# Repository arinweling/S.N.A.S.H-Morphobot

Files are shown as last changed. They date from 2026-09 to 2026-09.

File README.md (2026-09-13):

<!-- DON'T MODIFY ANYTHING ABOVE -->

<!-- Modify from here -->
<!-- ### EDL 2025 Project Submission Repository.

Change this file to include the relevant information of your project. Refer to SUBMISSION_INSTRUCTIONS.md file and follow it for your final submission. Make sure to pass the GitHub Actions. (The Docs Added should turn green and it should say "passing") -->

https://github.com/user-attachments/assets/5dc95bf6-1b18-49de-8811-edd3fce2244d

# S.N.A.S.H. - Your Friendly Neighbourhood MorphoBot
## MON-10
## Team Members:
- Sthiti Padhi
- Neel Bhavesh Rambhia
- Arin Prashant Weling
- Saumya Dharmesh Shah
- Harshil Singla

## Problem Statement and Solution:
### Problem Statement
Robots designed exclusively for ground travel or aerial operation often encounter significant challenges when faced with unpredictable or mixed environments. Ground-based robots may be unable to overcome obstacles or reach elevated areas, while aerial robots are limited by battery constraints and inefficiency during extended ground operations.

The problem is to create a robotic platform that can seamlessly transition between driving and flying, allowing it to navigate a wide range of terrains and obstacles efficiently. The system should provide the user with the ability to switch modes as needed to maximize energy efficiency and reach locations that would be inaccessible to single-mode robots.

### Solution
We developed **S.N.A.S.H.**, a multi-modal robotic system capable of:

- **Driving**: Increasing battery life and locomotive abilities for ground traversal.
- **Flying**: Quadcopter mode helps navigate over obstacles or difficult terrain.
- **Morphing**: A custom servo setup to switch between drive and drone configurations.

The system is controlled by a single flight controller that dynamically switches outputs to:
- 1 motor driver (controlling two motors via IN1 and two motors via IN2) (drive mode)  
- 4-in-1 ESC on SpeedyBee (flight mode)
- 4 Servo motors from their dedicated PCBs
based on mode-switch commands from the user through the RC transmitter.

### Folder Structure:
```plaintext
/Project-Root
├── /others
    ├── future_work.md/
    ├── learnings_takeaways.md/
    ├── user_manual.md/
    ├── README.md/
 
├── /3d_models               # laser cuts and 3d prints
    ├── Chassis/
    ├── Wheel_Assembly/
    ├── README.md/          
 
├── /pcb                    # pcb design files
    ├── PCB1/
    ├── Resources/
    ├── README.md/

├── /milestone reports

├── /inav

├── /Ardupilot                    # source folder
    ├── ArduCopter/         # we used ArduCopter and added files here
        ├── Copter.cpp
        ├── mode.cpp
        ├── mode_drive.cpp
        ├── mode_morph.cpp
        ├── mode_stabilize.cpp
        ├── README.md/      # describes the changes made, marked as 'EDL-MON10'
        └── ...
    
    ├── ArduPlane/  
    
    ├── ArduRover/
    
    ├── libraries/          # modified hwdef for gpio, default params
        ├── AP_HAL/
        ├── AP_HAL_ChibiOS/
        ├── AP_Motors/      # To use extra motor output or change motor functions - to be done here
        └── ...
    
    ├── modules/            
    
    ├── Tools/              # Developer tools, test scripts, MAVProxy, etc.
    
    ├── build/              # Build scripts and configuration
    
    ├── docs/               # Documentation
    
    ├── wscript             # Waf build system entry point
    └── README.md           # Project overview and setup instructions

```

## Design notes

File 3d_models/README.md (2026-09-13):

# 3D Models
This directory contains all the STEP files used for the mechanical design of the Morphobot.

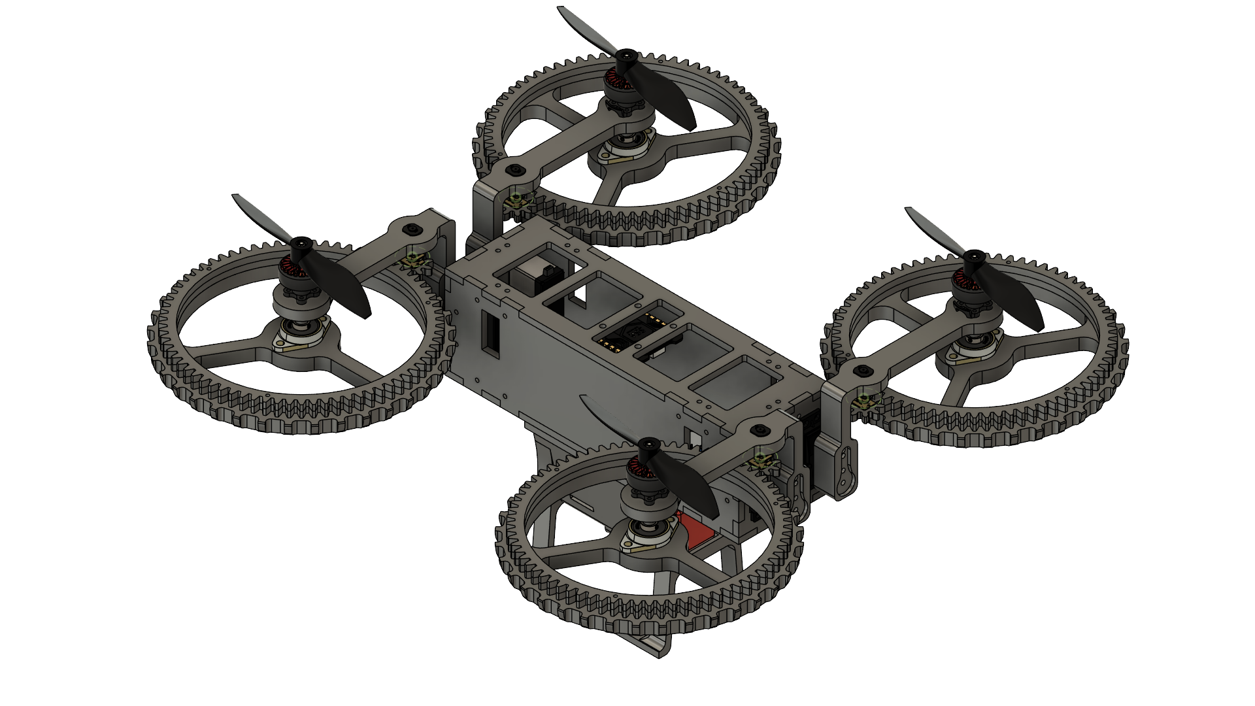
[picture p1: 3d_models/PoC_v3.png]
Complete Assembly


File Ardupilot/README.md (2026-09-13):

##
# Ardupilot Firmware:
##
It is a versatile and feature-rich firmware that supports various types of aircraft. Firmware for Speedybee F4 V3/V4 can be found in the Ardupilot firmware repository. 

Given the dual nature of a Morphobot (both ground and aerial operations), **Ardupilot** is likely the best choice. It supports VTOL (Vertical Takeoff and Landing) operations and can handle both ground and aerial modes effectively. This makes it ideal for a Morphobot that needs to switch between driving and flying. 

The entire Ardupilot documentation is available on: <https://ardupilots.org/copter/docs/common-speedybeef4-v3.html>

Codes are available in the Developers' community for Ardupilot Firmware. We have used that as the base model and added/ modified the codes for our usage. 

The Arducopter documentation information is available at:

<https://ardupilot.org/copter/>

<https://ardupilot.org/dev/docs/learning-the-ardupilot-codebase.html> 

These websites give all information about the codes available. 

We were majorly concerned with the Copter model with additions of Drive Mode and Morphing Mode.

## Wiring Diagram 
# 

##
# **Loading ArduPilot onto the board[¶](https://ardupilot.org/copter/docs/common-speedybeef4-v3.html#loading-ardupilot-onto-the-board)**
Initial firmware load can be done with DFU by plugging in USB with the bootloader button pressed. Then you should load the “with\_bl.hex” firmware, using your favourite DFU loading tool.

Once the initial firmware is loaded you can update the firmware using any ArduPilot ground station software. Updates should be done with the xxxxxxxxxx.apj firmware files.

## Compiling Ardupilot Firmware Code:
In Linux:

Open terminal in the folder containing the Ardupilot Firmware Code and Run the following commands:

- ./waf configure –-board speedybeef4v4
- ./waf copter –-board speedybeef4v4

Any syntax or firmware errors will be highlighted in one of these. If both commands are executed correctly, the code is ready to be uploaded onto SpeedyBee.

## Uploading Ardupilot Firmware Code to SpeedyBee:
1) On Linux using Terminal: Connect the SpeedyBee to the PC via USB and run the following command:
- ./waf copter –upload
1) On Windows: In the Ardupilot Firmware Folder, go to Build → SpeedyBeeF4V4 → Bin. Find the arducopter\_with\_bl.hex file and send it to Windows. Upload this file onto SpeedBeeF4V4 using STM32Programmer.

# After flashing the code:
Once the code is flashed, the bot is ready to be operated. You can run various sets of checks/ exercises to ensure correctness of your code. This can be done using the Mission Planner software.

More information on Mission Planner can be found at: <https://ardupilot.org/planner/>

We used Mission Planner for Accelerometer Calibration, Motor Testing, Radio Control Settings and Calibration ,etc.

# Important Cares and Caveats:
## Arming:
Ensure that the bot arms correctly on switching to any of the drone modes. If that is not the case, it is a good practice to check the connections and battery. You can connect to Mission Planner and check if there is Pre Arm failure. There will be a set of errors visible (gyros not calibrated, RC absent, Battery Voltage Low, etc.). You can then troubleshoot the problems.

More information can be obtained at: <https://ardupilot.org/copter/docs/arming_the_motors.html>

## Motor Configuration and Testing:
Motors and Propellers must be connected in proper order and direction for the drone mode. We used the Quad Frame Class and Hexa Frame Type for our bot. More information is available at: <https://ardupilot.org/copter/docs/connect-escs-and-motors.html/>

In the full parameter list of the Config tab of Mission Planner, you can see all the frame types and the corresponding toke number. This token number will be written in the config.h file before building the firmware code. Then look at the servo 1 to 4 parameters. You need to assign each of them to the motors M1 to M4 (values 34 to 37). This can be done iteratively based on the diagram of the chosen frame from the above website and by testing the Motors. This can be done in the Setup tab in the Test Motors option. Testing motors iteratively and varying the assigned tokens you can assign the correct number to the motor and the direction (CW / CCW). These values must also be written in the config.h file.

# ArduPilot Project

<a href="https://ardupilot.org/discord">

    

   





 







ArduPilot is the most advanced, full-featured, and reliable open source autopilot software available.
It has been under development since 2010 by a diverse team of professional engineers, computer scientists, and community contributors.
Our autopilot software is capable of controlling almost any vehicle system imaginable, from conventional airplanes, quad planes, multi-rotors, and helicopters to rovers, boats, balance bots, and even submarines.
It is continually being expanded to provide support for new emerging vehicle types.

## The ArduPilot project is made up of: ##

- ArduCopter: [code](https://github.com/ArduPilot/ardupilot/tree/master/ArduCopter), [wiki](https://ardupilot.org/copter/index.html)

- ArduPlane: [code](https://github.com/ArduPilot/ardupilot/tree/master/ArduPlane), [wiki](https://ardupilot.org/plane/index.html)

- Rover: [code](https://github.com/ArduPilot/ardupilot/tree/master/Rover), [wiki](https://ardupilot.org/rover/index.html)

- ArduSub : [code](https://github.com/ArduPilot/ardupilot/tree/master/ArduSub), [wiki](http://ardusub.com/)

- Antenna Tracker : [code](https://github.com/ArduPilot/ardupilot/tree/master/AntennaTracker), [wiki](https://ardupilot.org/antennatracker/index.html)

## User Support & Discussion Forums ##

- Support Forum: <https://discuss.ardupilot.org/>

- Community Site: <https://ardupilot.org>

## Developer Information ##

- Github repository: <https://github.com/ArduPilot/ardupilot>

- Main developer wiki: <https://ardupilot.org/dev/>

- Developer discussion: <https://discuss.ardupilot.org>

- Developer chat: <https://discord.com/channels/ardupilot>

## Top Contributors ##

- [Flight code contributors](https://github.com/ArduPilot/ardupilot/graphs/contributors)
- [Wiki contributors](https://github.com/ArduPilot/ardupilot_wiki/graphs/contributors)
- [Most active support forum users](https://discuss.ardupilot.org/u?order=post_count&period=quarterly)
- [Partners who contribute financially](https://ardupilot.org/about/Partners)

## How To Get Involved ##

- The ArduPilot project is open source and we encourage participation and code contributions: [guidelines for contributors to the ardupilot codebase](https://ardupilot.org/dev/docs/contributing.html)

- We have an active group of Beta Testers to help us improve our code: [release procedures](https://ardupilot.org/dev/docs/release-procedures.html)

- Desired Enhancements and Bugs can be posted to the [issues list](https://github.com/ArduPilot/ardupilot/issues).

- Help other users with log analysis in the [support forums](https://discuss.ardupilot.org/)

- Improve the wiki and chat with other [wiki editors on Discord #documentation](https://discord.com/channels/ardupilot)

- Contact the developers on one of the [communication channels](https://ardupilot.org/copter/docs/common-contact-us.html)

## License ##

The ArduPilot project is licensed under the GNU General Public
License, version 3.

- [Overview of license](https://ardupilot.org/dev/docs/license-gplv3.html)

- [Full Text](https://github.com/ArduPilot/ardupilot/blob/master/COPYING.txt)

## Maintainers ##

ArduPilot is comprised of several parts, vehicles and boards. The list below
contains the people that regularly contribute to the project and are responsible
for reviewing patches on their specific area.

- [Andrew Tridgell](https://github.com/tridge):
  - ***Vehicle***: Plane, AntennaTracker
  - ***Board***: Pixhawk, Pixhawk2, PixRacer
- [Francisco Ferreira](https://github.com/oxinarf):
  - ***Bug Master***
- [Grant Morphett](https://github.com/gmorph):
  - ***Vehicle***: Rover
- [Willian Galvani](https://github.com/williangalvani):
  - ***Vehicle***: Sub
  - ***Board***: Navigator
- [Michael du Breuil](https://github.com/WickedShell):
  - ***Subsystem***: Batteries
  - ***Subsystem***: GPS
  - ***Subsystem***: Scripting
- [Peter Barker](https://github.com/peterbarker):
  - ***Subsystem***: DataFlash, Tools
- [Randy Mackay](https://github.com/rmackay9):
  - ***Vehicle***: Copter, Rover, AntennaTracker
- [Siddharth Purohit](https://github.com/bugobliterator):
  - ***Subsystem***: CAN, Compass
  - ***Board***: Cube*
- [Tom Pittenger](https://github.com/magicrub):
  - ***Vehicle***: Plane
- [Bill Geyer](https://github.com/bnsgeyer):
  - ***Vehicle***: TradHeli
- [Emile Castelnuovo](https://github.com/emilecastelnuovo):
  - ***Board***: VRBrain
- [Georgii Staroselskii](https://github.com/staroselskii):
  - ***Board***: NavIO
- [Gustavo José de Sousa](https://github.com/guludo):
  - ***Subsystem***: Build system
- [Julien Beraud](https://github.com/jberaud):
  - ***Board***: Bebop & Bebop 2
- [Leonard Hall](https://github.com/lthall):
  - ***Subsystem***: Copter attitude control and navigation
- [Matt Lawrence](https://github.com/Pedals2Paddles):
  - ***Vehicle***: 3DR Solo & Solo based vehicles
- [Matthias Badaire](https://github.com/badzz):
  - ***Subsystem***: FRSky
- [Mirko Denecke](https://github.com/mirkix):
  - ***Board***: BBBmini, BeagleBone Blue, PocketPilot
- [Paul Riseborough](https://github.com/priseborough):
  - ***Subsystem***: AP_NavEKF2
  - ***Subsystem***: AP_NavEKF3
- [Víctor Mayoral Vilches](https://github.com/vmayoral):
  - ***Board***: PXF, Erle-Brain 2, PXFmini
- [Amilcar Lucas](https://github.com/amilcarlucas):
  - ***Subsystem***: Marvelmind
- [Samuel Tabor](https://github.com/samuelctabor):
  - ***Subsystem***: Soaring/Gliding
- [Henry Wurzburg](https://github.com/Hwurzburg):
  - ***Subsystem***: OSD
  - ***Site***: Wiki
- [Peter Hall](https://github.com/IamPete1):
  - ***Vehicle***: Tailsitters
  - ***Vehicle***: Sailboat
  - ***Subsystem***: Scripting
- [Andy Piper](https://github.com/andyp1per):
  - ***Subsystem***: Crossfire
  - ***Subsystem***: ESC
  - ***Subsystem***: OSD
  - ***Subsystem***: SmartAudio
- [Alessandro Apostoli ](https://github.com/yaapu):
  - ***Subsystem***: Telemetry
  - ***Subsystem***: OSD
- [Rishabh Singh ](https://github.com/rishabsingh3003):
  - ***Subsystem***: Avoidance/Proximity
- [David Bussenschutt ](https://github.com/davidbuzz):
  - ***Subsystem***: ESP32,AP_HAL_ESP32
- [Charles Villard ](https://github.com/Silvanosky):
  - ***Subsystem***: ESP32,AP_HAL_ESP32

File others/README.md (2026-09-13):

# /others

This folder contains additional resources, documentation, and references that supported the development of the Morphobot project.

---

## 🔧 Future Work

The Morphobot project has reached a significant milestone, but there are several exciting directions for future development:
---

### Future Work
- Improve flange bearing support to enhance wheel stability during movement.  
- Enable independent servo control using additional PWM pins for precise leg alignment.  
- Optimize power distribution by evaluating servo current needs and consolidating buck converters.  
- Add features like FPV camera, GPS, and companion computer for autonomy and real-time feedback.  
### Learnings and takeaways
### Things Learned the Hard Way
- Team management, communication, and clear work allotment are key to project success.  
- Proper measurements, simulations, and testing are essential to avoid costly design errors.  
- Time management is crucial, balancing the project with other commitments and deadlines.  

### Things Learned the Easy Way
- Passion for the project kept us motivated and driven throughout.  
- Research, clear understanding, and communication within the team are critical for project success.  

### User Manual

### Wiring diagrams and Chassis photos

### 🛠 Maintenance

- Regularly check:
  - Servo calibration and alignment
  - Structural integrity of the arms and chassis
  - Battery voltage and ESC health

---

For any specific customizations or questions, refer to the `README.md` inside `/src/ArduCopter` for detailed code modifications and logic flow.

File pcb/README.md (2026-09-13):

## Description

The PCB has two Buck regulator IC's (LMR14050) that step down the voltage from 14.8V-16.8V (4S LiPo Battery) to 7.4V in order to power the Servo Motors. Since there are 4 servo motors, two PCB's (and thus 4 IC's) are used for the same. The circuit is simply designed from the datasheet specifications given. 

The PCB was designed on KiCad 8.0 and maufactured from PCB Power (external vendor) since via size on IC footprint was quite small.

## How to use this directory

Download or clone this repository to get all the necessary files. Edit the "fp-lib-table" and "sym-lib-table" files to include _your_ path for the symbols and footprints required. All symbol and footprint files are within the "Resources" directory.

## Quick Verification of the PCB after Manufacturing

Testpoints are provided on the PCB for quick verification of the output voltage. LED's are also present and can be used as a visual indicator but not necessarily reliable (a range of voltage will turn it on, you can't assume it is 7.4V only). Also, the LED is optional and may be removed or not soldered and the PCB would work fine.

## Calculations for the circuit

#### LMR14050 Buck Switching Regulator IC  

Input Voltage - 14.8V 

Output Voltage - 7.4V 

Max Output Current - 3.8A 

Transient Response - 5% 

Soft-Start time - 5ms 

#### Output Voltage Setpoint: 

R_FBT = (14.8-0.75)/0.75 * R_FBB 

So, R_FBT = 160k & R_FBB = 18k 

#### Output Inductor Selection: 

L=4.7uH (available from WEL) 

Lmin =  [(14.8-7.4)/(3.8*0.4)] * [7.4/(14.8*f)] = 2.4342 / f 

For Lmin = 4.7uH => f = 517kHz 

Take Switching Frequency 750kHz => Lmin = 3.24uH 

#### Switching Frequency: 

f = 750kHz 

R_T = 32.4k 

Closest available R_T = 33k => f=732kHz 

#### Output Capacitor: 
100uF (25V) x2 in Parallel 

#### Schottky Diode: 
5-6A rated Schottky diode 

<https://www.googleadservices.com/pagead/aclk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>

#### Input capacitor: 
10uF (35V) + 0.1uF for high frequency filtering 

#### Bootstrap: 
0.1uF (16V) 

## Testing Plan

1. Solder only one IC and test it before soldering the other one 
2. Use DC Power Supply and give 14.8V input voltage in CV mode by attaching to XT60 using alligator clips 
3. Attach a high resistance (10kOhm) to output and turn on the power supply (LED should light up) 
4. Check VIN and GND test points to confirm 14.8V and 0V 
5. Check VOUT test point to confirm 7.4V 
6. Decrease resistance to check performance when higher current is drawn 
7. Decrease resistance till 2.2 Ohm (use power resistor since current capacity is exceeded at such low resistance 
8. Apply a PWM signal to center jumper (J4) and check the signal using oscilloscope on Pin1 of J2 and J3 
9. Remove power supply and attach 4S LiPo battery. Check the output voltage again and performance with 2.2Ohm again 
10. Remove resistor and attach servo motor. Give a PWM using any simple microcontroller and check correct functioning. 
11. Attach the servo arm and apply heavy load to make the servo motor stall. Check that IC is working properly even when stalling. 
12. Repeat for 2nd IC.

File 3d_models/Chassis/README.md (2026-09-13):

Chassis components:
- [Top Plate](./Top_Plate)
- [Bottom Plate](./Bottom_Plate)
- [Servo Plate](./Servo_Plate)
- [Side Plate](./Side_Plate)
- [L-Joint](./L_Joint)
- [Battery Box](./Battery_Box)

The battery box and the L-joints were 3D printed, while the other components were laser cut.
All laser cut components are from 5mm acrylic sheet. The L-joints were printed at max infill (90%) while the battery box at the normal 30%.

The chassis was assembled using
- 12 L-Joints,
- 2 servo plates,
- 2 side plates,
- 1 top plate,
- 1 bottom plate and
- 1 battery box,<br>
all of which were fastened using M3 nuts & bolts.

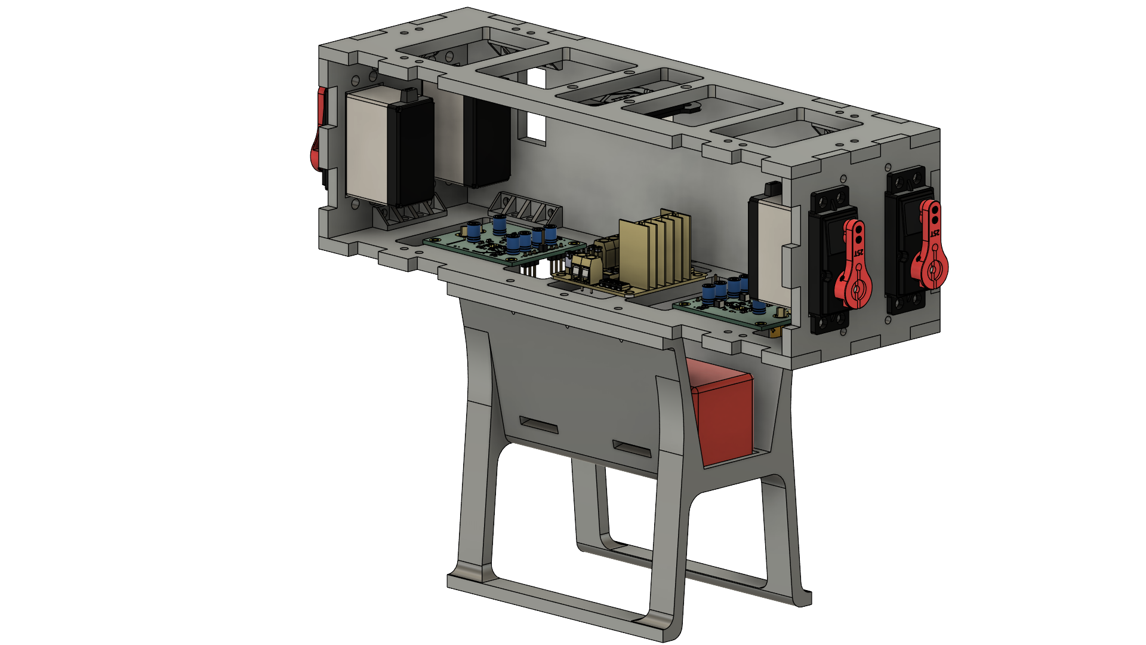
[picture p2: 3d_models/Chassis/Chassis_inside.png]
Interior of the Chassis


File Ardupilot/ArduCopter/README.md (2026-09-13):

# ArduCopter: Drive & Morph Mode Integration

---

## Official ArduPilot Resources

- [ArduCopter Documentation](https://ardupilot.org/copter/)
- [Learning the ArduPilot Codebase](https://ardupilot.org/dev/docs/learning-the-ardupilot-codebase.html)

We primarily used the **Copter**, with **custom flight modes** for **Drive** and **Morph**.

---

## Custom Flight Modes

### Default + Custom Modes
ArduCopter provides various flight modes like **Stabilize**, **Acro**, **Pos Hold**, and **Acro**. We added two new modes:

- **Drive Mode**
- **Morph Mode**

### Adding New Modes
##
# **Different Flight Modes[¶](https://ardupilot.org/copter/docs/common-speedybeef4-v3.html#loading-ardupilot-onto-the-board)**
Arducopter has various flight modes such as Stabilize, Acro, Pos Hold, Loitre, etc. We added Drive and Morph as 2 different modes to these itself.
## Adding New Modes:
The instructions are available at:

<https://ardupilot.org/dev/docs/apmcopter-adding-a-new-flight-mode.html> 

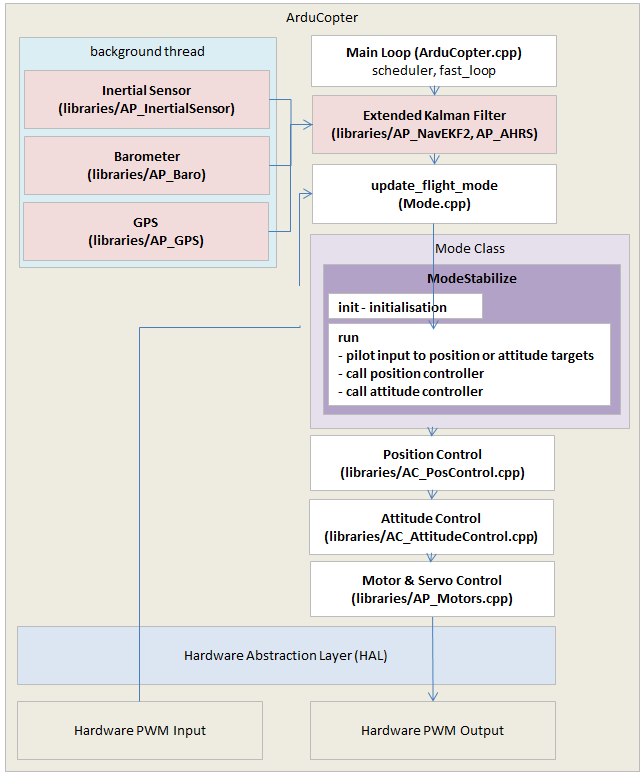
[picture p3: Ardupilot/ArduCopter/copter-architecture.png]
Adding New Mode to Arducopter


---

## RC Channel Mapping

### Mode Switching (via SB, SC, Channel 8)

| **(SB + SC)/2 PWM** | **Mode** |
|---|---|
| 1000 - 1230 | Drive |
| 1230 - 1360 | Morph Up (RC Channel 8 = 2000) |
| 1360 - 1490 | Stabilize |
| 1490 - 1620 | Acro |
| 1620 - 1749 | Morph Down (RC Channel 8 = 1000) |
| 1750 - 2000 | Pos Hold |

Mode assignments are configured in `config.h` and mapped in `Parameters.cpp`.

RC Channel 5 (`SA`) is assigned for **arming the BLDC motors**.
RC Channel 8 is assigned for **direction of morphing**.
---

## Motor Integration

### Motor Types:

1. **DC Motors (Drive Mode)** — Controlled via **L298N**, supports **50 Hz** & **400 Hz**.
2. **BLDC Motors (Drone Mode)** — Standard drone motors, use **400 Hz**.
3. **Servo Motors (Morph Mode)** — Requires **50 Hz** operation.

### BLDC Motors (Pins M1 to M4)
- Standard motor pins for SpeedyBee.

### Servo Motors (Pins M6, M8)
- To use Servo motors in flight modes, we have disabled the SRV_Channels::output_ch_all() in the main motor output function.
- Set output frequency to **50 Hz**:
```cpp
hal.rcout->enable_ch(5);
hal.rcout->enable_ch(7);
hal.rcout->set_output_mode((1UL << 5)|(1UL << 7), AP_HAL::RCOutput::MODE_PWM_NORMAL);
hal.rcout->set_freq((1UL << 5), 50);
hal.rcout->set_freq((1UL << 7), 50);
```
- To write PWM:
```cpp
hal.rcout->write(5, pwm_value);
hal.rcout->write(7, pwm_value);
```

### DC Motors (GPIO Pins 59-62)
- Used alternate pins (R3, T3, R6, T6) configured in `hwdef.dat`:
```c
PC10 ARIN OUTPUT GPIO(59)
PC11 NEEL OUTPUT GPIO(60)
PC6  ARIN_1 OUTPUT GPIO(61)
PC7  NEEL_1 OUTPUT GPIO(62)
```
- Initialize as output pins:
```cpp
hal.gpio->init();
hal.gpio->pinMode(59, HAL_GPIO_OUTPUT);
...
hal.gpio->write(59, t1);
...
```

---

## Drive Mode Logic

Defined in `mode_drive.cpp`

- `init()` is called once
- `run()` is executed at **400 Hz**

### Behavior:
- Using **pitch** for forward/backward motion.
- Using **roll** to turn:
  - Roll ∈ [1250,1750] = Go straight
  - Roll < 1250 = Turn left
  - Roll > 1750 = Turn right

- **Servo PWM values** for drive:
  - Channel 5 = `2000`
  - Channel 7 = `950`

---
GPIO pins are used by re-configuring rx, tx pins in hwdef file.
```cpp
\# USART6 (GPS)
PC6 USART6\_TX USART6
PC7 USART6\_RX USART6

\# USART3 (CAM)
PC10 USART3\_TX USART3 NODMA
PC11 USART3\_RX USART3 NODMA
```
We will change above definitions:

```cpp
PC10 ARIN OUTPUT GPIO(59)
PC11 NEEL OUTPUT GPIO(60)

PC6 ARIN\_1 OUTPUT GPIO(61)
PC7 NEEL\_1 OUTPUT GPIO(62)
```

There are 58 pre-defined GPIO pins on SpeedyBeeF4V4. Thus while creating new GPIO pins, we start numbering from 59 onwards.
The left-right logic is implemented using above values on GPIO pins:
```cpp
hal.gpio->write(59, t1);
hal.gpio->write(60, t2);
hal.gpio->write(61, t3);
hal.gpio->write(62, t4);
```

## Morph Mode Logic
SpeedyBee also has Motor pins M5 to M8 (they can also serve as servo pins) that can be used to connect Motors.

Since Servo Motors must be operated at 50 Hz, we have to choose 2 of the above pins (M6 and M8) and change the operating frequency from 400 Hz to 50 Hz.

- Gradual servo PWM change:
  - Morph Up: `2000 → 1050` & `950 → 1900`
  - Morph Down: reverse

- Only runs every 8th loop for **50 Hz compatibility**
- **DC Motors are stopped** during morph:
```cpp
hal.gpio->write(59, 0);
hal.gpio->write(60, 0);
hal.gpio->write(61, 0);
hal.gpio->write(62, 0);
```
- Triggered by RC Channel 8:
  - 2000 = Morph Up
  - 1000 = Morph Down

---
To implement PWM to servos we have to write the following code in the different modes where we are using these motor pins:
They are enabled as pwm pins and basic ***hal.rcout->write()*** function is used.
```cpp
hal.rcout->enable\_ch(5);
hal.rcout->enable\_ch(7);
```
AP\_HAL::RCOutput::MODE\_PWM\_NORMAL);
```cpp
hal.rcout->set\_output\_mode((1UL << 5)|(1UL << 7), AP\_HAL::RCOutput::MODE\_PWM\_NORMAL);
hal.rcout->set\_freq((1UL << 5), 50);
hal.rcout->set\_freq((1UL << 7), 50);
```

Whenever we want to write a PWM value to these motor pin channels, we can use:
```cpp
hal.rcout->write(5, pwm\_value);
hal.rcout->write(7, pwm\_value);
```
## Drone Modes Used

- [Stabilize Mode](https://ardupilot.org/copter/docs/stabilize-mode.html)
- [Acro Mode](https://ardupilot.org/copter/docs/acro-mode.html)
- [PosHold Mode](https://ardupilot.org/copter/docs/poshold-mode.html)

---
Servo pwm also sent in drone modes to keep legs upright in position.

## Parameter Setup (config.h)

Update using **Mission Planner** or directly edit `default.param` in hwdef files:

### Required Settings:
```ini
ARMING_CHECK,1047038
AHRS_ORIENTATION,8
COMPASS_AUTO_ROT,0
COMPASS_AUTODEC,0
COMPASS_ENABLE,0
FRAME_CLASS,1
FRAME_TYPE,3
RC5_OPTION,153
SERVO1_FUNCTION,33
SERVO2_FUNCTION,36
SERVO3_FUNCTION,34
SERVO4_FUNCTION,35
SERVO6_FUNCTION,0
SERVO8_FUNCTION,0
SERVO9_FUNCTION,0
```

### Notes:
- `AHRS_ORIENTATION = 8` (Roll180) due to inverted mount
- `COMPASS_ENABLE = 0` (No compass)
- Servo function values map ESCs to PWM outputs

---

> For more details, refer to the [official ArduPilot flight modes guide](https://ardupilot.org/copter/docs/flight-modes.html).

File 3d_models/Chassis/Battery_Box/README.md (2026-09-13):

Battery Box

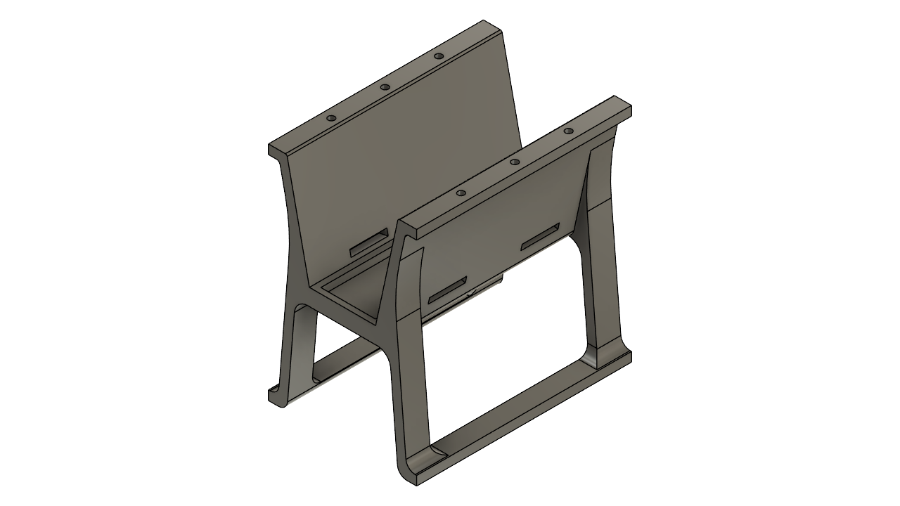
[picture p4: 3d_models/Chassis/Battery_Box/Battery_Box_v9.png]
Battery Box


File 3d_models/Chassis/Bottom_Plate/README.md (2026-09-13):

Bottom Plate

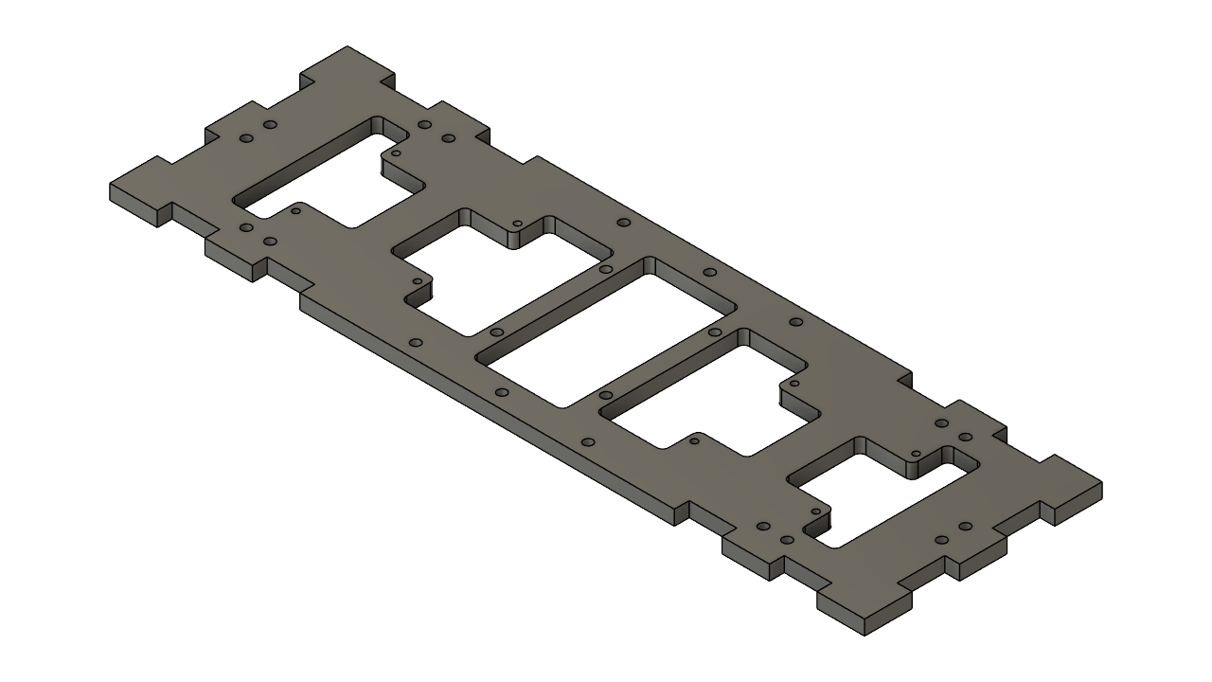
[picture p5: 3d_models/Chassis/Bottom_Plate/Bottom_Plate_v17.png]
Battery Box


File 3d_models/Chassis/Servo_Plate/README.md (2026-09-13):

Servo Plate

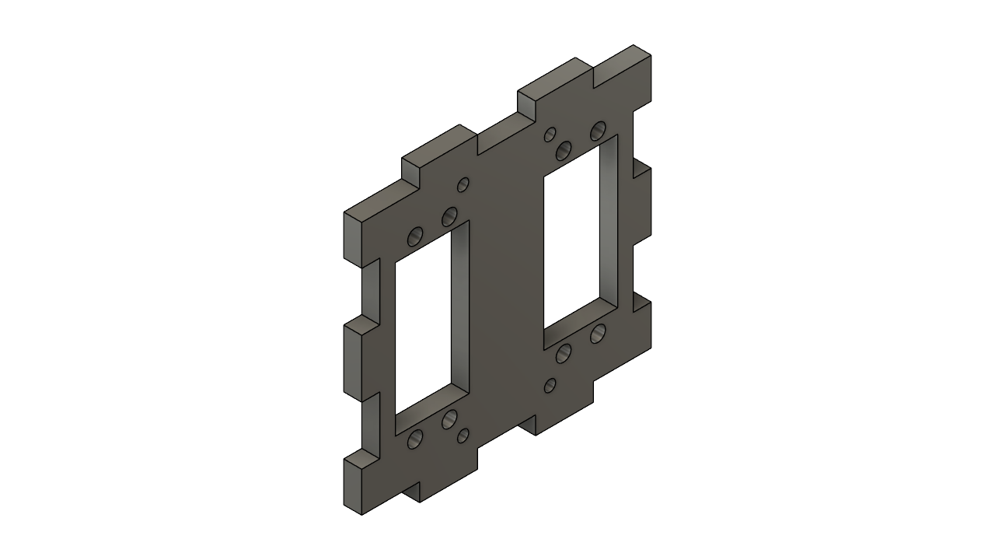
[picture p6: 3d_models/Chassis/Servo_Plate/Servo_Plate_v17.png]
Servo Plate


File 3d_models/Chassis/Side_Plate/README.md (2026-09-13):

Side Plate<br>
Any text engravings can be directly added in LaserCAD
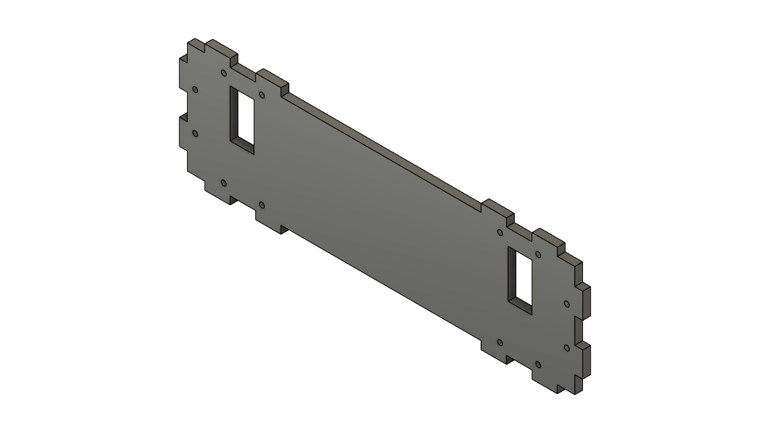
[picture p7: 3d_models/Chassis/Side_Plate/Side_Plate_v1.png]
Side Plate


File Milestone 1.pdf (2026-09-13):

## EE344: Milestone 1

MON - 10
Arin Weling, Harshil Singla, Saumya Shah, Sthiti Padhi, Neel Rambhia

Indian Institute of Technology Bombay

Problem Description

Auto-transforming Robot Toy

- To build a physically transforming robotic toy which

transforms on user’s indication.

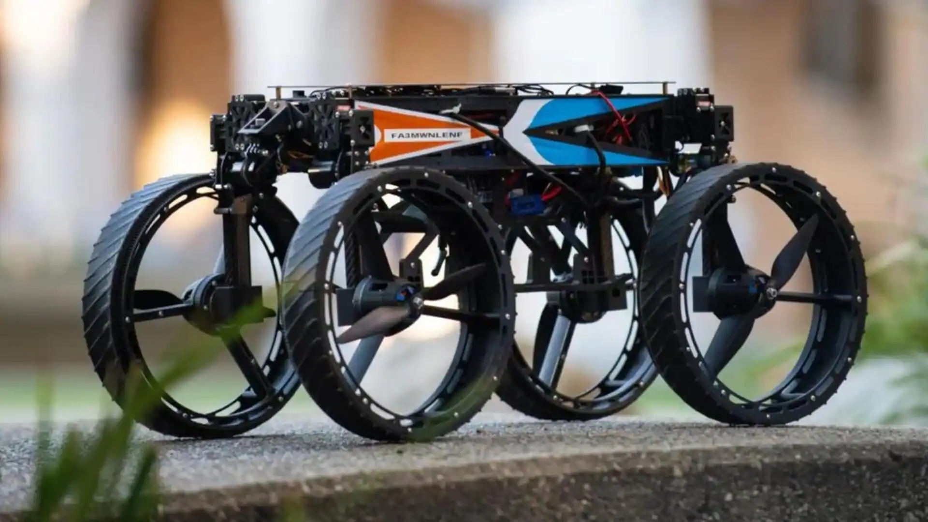
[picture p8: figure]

Figure 1: Caltech M4 Morphobot

What is the problem we are solving?

Multi-terrestrial Travel and Transformation

- A ground vehicle cannot move on all terrains and an aerial

vehicle has limited flight time.
- Incorporating both modes of travel into singular vehicle form

Possible Applications:
- Drives through debris and flies over obstacles to assist in search and rescue operations.
- Moves stealthily on the ground and takes off for aerial monitoring in restricted areas.
- As entertainment in the form of an autotransforming toy etc.

Proposed Solution

Our idea of an auto-transforming toy is one which can travel on land and in air with a smooth transition (morphosis) between them. We are inspired from the Caltech M4[1]. (https://www.nature.com/articles/s41467-023-39018-y) The toy has 2 distinct modes of operation (ground mode and aerial mode). The

morphobot can be controlled manually using a joystick and has flight video feed, for an intuitive user experience. We aim to make it rigid and cost effective to attract target users.

Also other mechanisms (including locking mech.) have been explored for transformation. One of the plausible designs is that of a hybrid mobility robot. [Video Link] (https://youtu.be/f1GSzysrYtw?si=lYR7eUmgE5Z5kRDF)

We are going with modified Caltech M4 design, with only drive and drone modes.

How will we achieve the specification?

- We aim to integrate the advantages of ground and aerial

modes into a single vehicle.
- The transition consists of rotating the legs by 90◦
to align
parallel to the body, allowing the propellers to function in drone mode.
- To reduce costs, we will operate the bot using a single

µcontroller. The overall weight has been minimized by eliminating redundant components.
- We have conducted essential calculations to determine the

optimal motors for both modes and their transition. The chassis and leg assembly also require significant design considerations.

Design Choices - Caltech M4

Advantages:
- M4 has dedicated wheels, allowing for better ground control,

sharp turns, and smooth navigation.
- M4 design allows easier modifications or upgrades (only 2

modes) - cost efficient and smaller design

Disadvantages:
- Bulky size of M4 has to be scaled for practical use
- Servo mechanism for transformations has to be reduced from

two hip servos to one (limited modes)

Novelty:
- Hip servos used for the transformation and extension of M4

configurations
- Support structures to balance chassis wt. and individual
control of motors and propellers | 6/24

Design Choices - Hybrid Mobility Robot

Advantages:

- The tank belt allows wheels more mobility in rough terrain
- Transforming mechanism avoids ground impact

Disadvantages

- The exoskeleton design makes it harder to integrate drone

components and places more emphasis on mechanical design
- Difficult to modify design according to our requirements

(mech.)

Novelty

- Linear actuator for extending propellers to quad-copter mode
- Servo to lower the chassis to ground level to avoid force

impact

Design Choices - Microcontroller

- STM32:
- We looked at LoRa and STM32 for commands sending but the LoRa was overkill and we decided to go for simpler design
- SpeedyBee had adequate processing and STM was removed to reduce redundant wt.
- RPi Pico:
- It has a complete OS which is redundant for our purpose
- Every 10 ms, it executes commands other than flight control
- ESP32 wifi:
- The wifi module can be used for commands but inadequate for video feed
- Additional hardware and integration with flight controller

We have decided to work with SpeedyBee as our main as well as
flight controller. It has adequate resources. | 8/24

Principle of Operation

Drive Mode

- The morphobot is capable of ground traversal with a speed

range of [0.5 m/s to 2.5 m/s].

- The support structures and chassis design enable, the bot

weight balanced by support when wheels leave ground.

Drone mode

- The bot morphs into a drone using high-torque servos, which

lift the tire assembly (our calculated max. possible torque of 35 kgcm).

- The drone has been designed (28cm X 28cm dimensions) for

indoor flight

Technical Details

Weight Constraints

- The morphobot will weigh upto 3 kg taking consideration of

all components and mechanical assembly - This was our primary consideration.
- 4S battery preferred over 6S to limit battery weight (234gm).

Power Constraints

- 4S battery of 2200mAh taken appropriate for bldc motor

(min. 1500mAh).

- 4S battery chosen over 3S to provide enough power for

adequate thrust for 3kg bot (bldc motors)

Technical Details - Drone Mode

- The BLDC motors provide a thrust of 750 gf per motor at

65% throttle.
- The propeller size suitable with the above motor is 6-inch.
- BLDC motor we have chosen is 2550KV with 4S battery (FS

2207.5 Turbo).

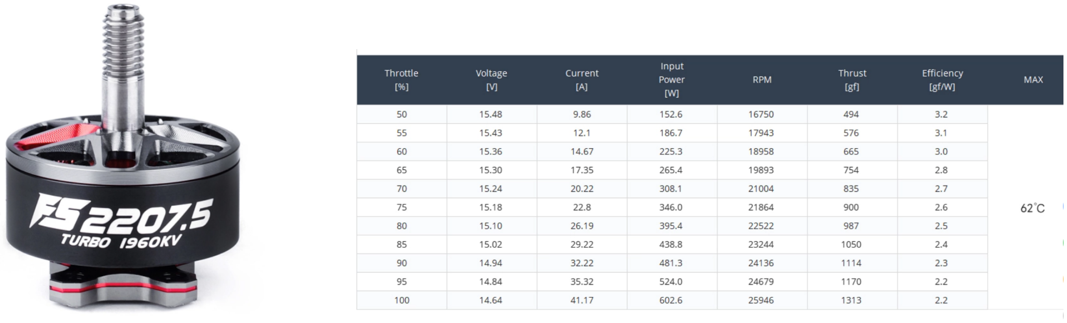
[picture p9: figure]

(a) Motor for propeller | (b) Rating for motor

Technical Design: Circuit Diagram

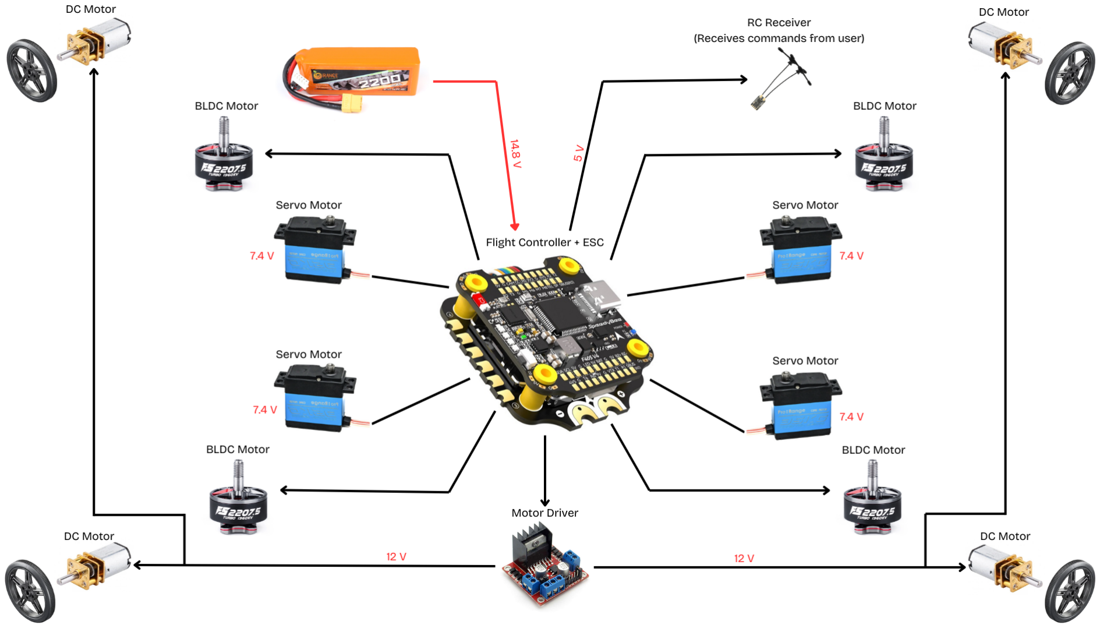
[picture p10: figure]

Figure 3: Circuit Diagram

Technical Design: Drive Mode

- Taking propeller diameter 6 inches, wheel diameter 16cm
- Rim thickness - approx. 1-2 cm, Wheel width taken as -

approx. 3-4 cm
- High torque and low RPM chosen - minimal wt added

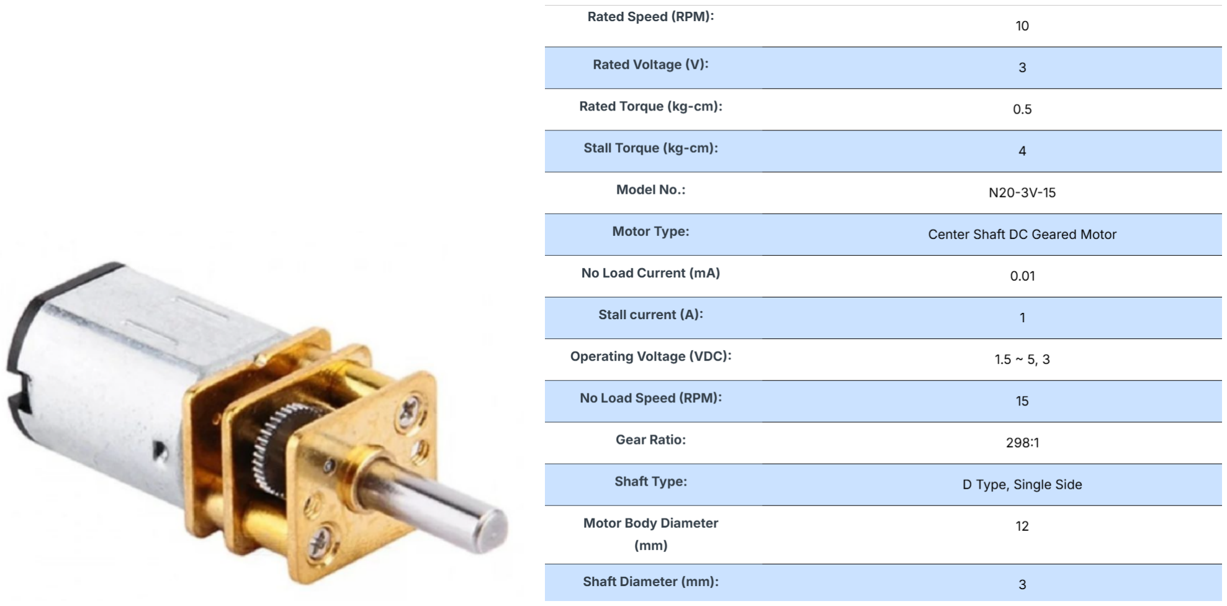
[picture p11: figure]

(a) DC motor | (b) Specs for DC motor

Technical Design: Morphing

- Approximate max. torque to be developed is 35 kgcm to lift

and hold tire assembly
- High torque servo motors to be used
- Possibility of using mechanical locking in the 2 modes

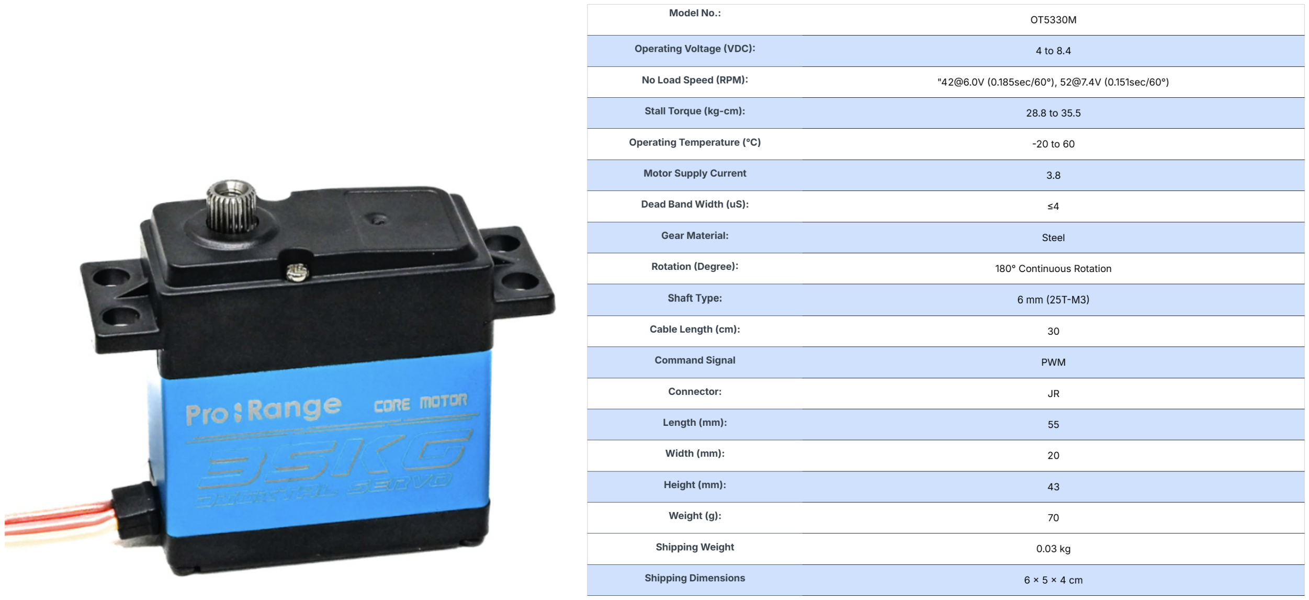
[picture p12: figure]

(a) Servo motor | (b) Specs for Servo motor

Technical Design: Mechanical Structure

- The chassis would be of the dimensions of 28 cm × 8 cm.
- In drone mode, entire structure stretches out to

28 cm × 28 cm.

- Height in the rover mode will be 18 cm.
- Structure should be made of tough but light material. We will

explore various options like sheet metal, carbon fibre, etc.
- Additional supports at the bottom of the chassis for smooth

transitions in between modes.

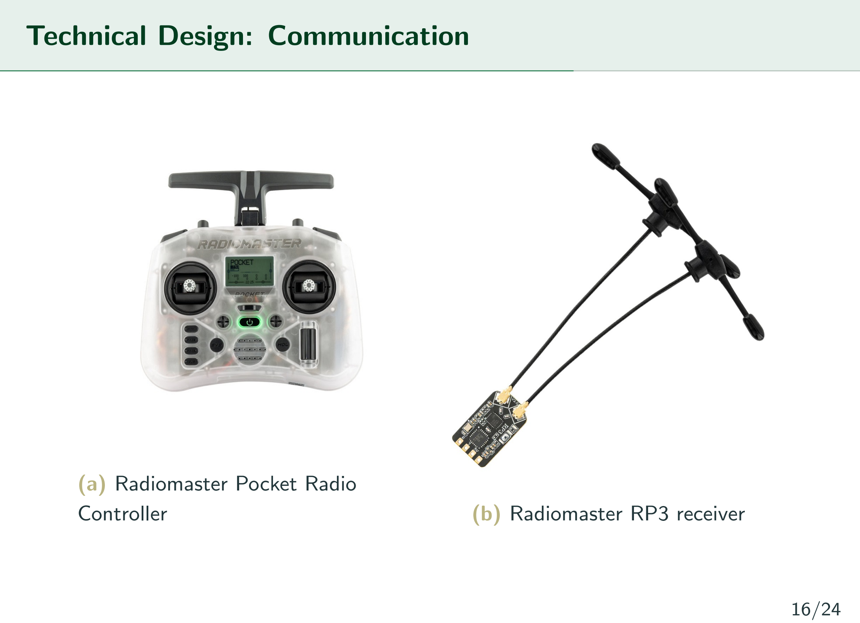
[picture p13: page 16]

Technical Design: Communication

(a) Radiomaster Pocket Radio
Controller | (b) Radiomaster RP3 receiver

Technical Design: Control

- We are planning to use ready-made flight controller. This

would ensure that our controller is compatible with the software ( eg: Ardupilot).
- SpeedyBee has 4 pins to be used for controlling propeller

motors and 4 other pins for drive control.
- Additional dedicated pin for servo control for transforming

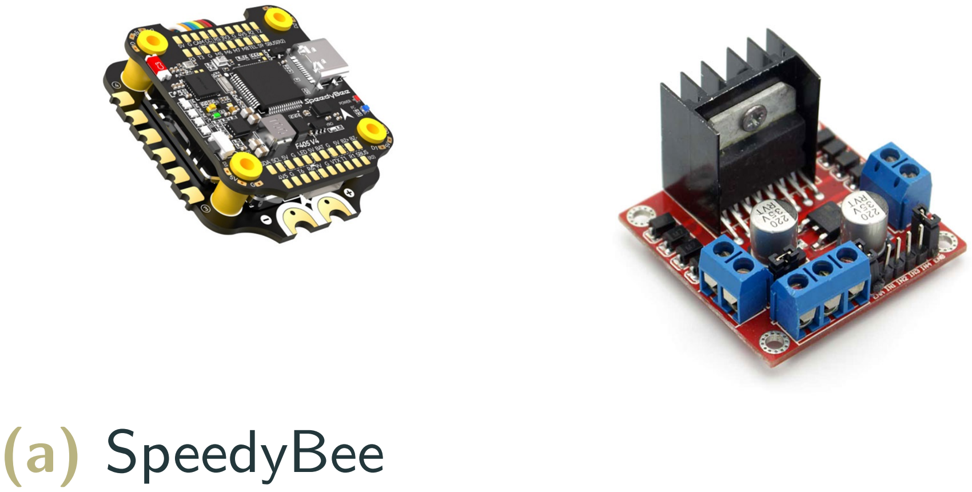
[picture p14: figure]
(a) SpeedyBee

F405 V4 BLS 55A
FC & ESC Stack
(b) L298N Motor
Driver | 17/24

Technical Design: Power Circuit

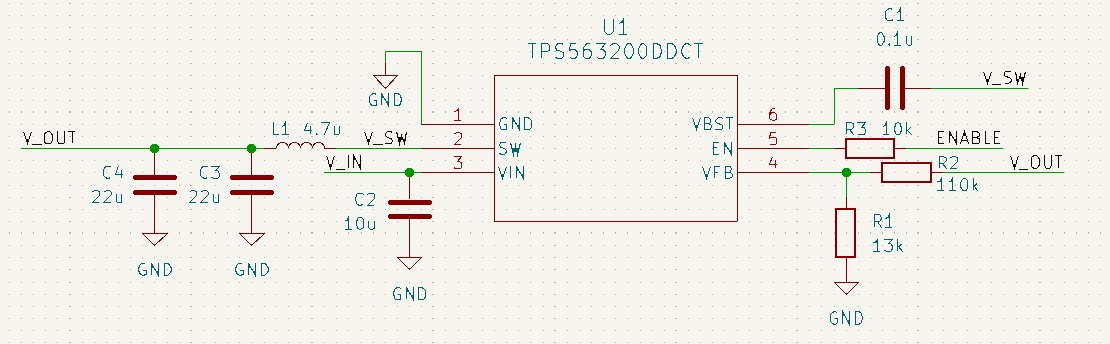
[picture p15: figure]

(a) Step-Down Regulator Circuit
- LiPo Battery (4S 40C 2200mAh)
- Step-Down Switching Regulator (14.8V to 7.4V)

Technical Design: Block Diagram

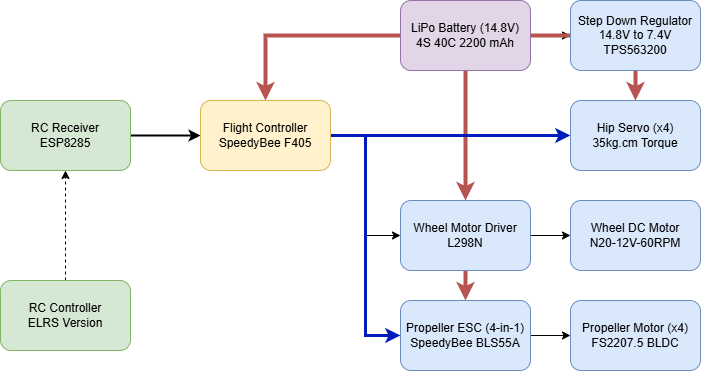
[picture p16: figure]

(a) Step-Down Regulator Circuit

Alternative Options: Communication

- Zigbee + STM: This was suitable to send commands with a

suitable range and as the main controller. This is a backup, as it is redundant. SpeedyBee provides the same capabilities.
- ESP32 (Wifi): A wifi module fits the indoor usage of

morphobot. There is also an option of ESPcam for video feed transfer over wifi. We are not using this to maintain minimal weight.
- FPV VTX and RTX: This is what we think would be ideal

for stable video feed. Since, FPV systems are generally used for drones.

Gantt Chart

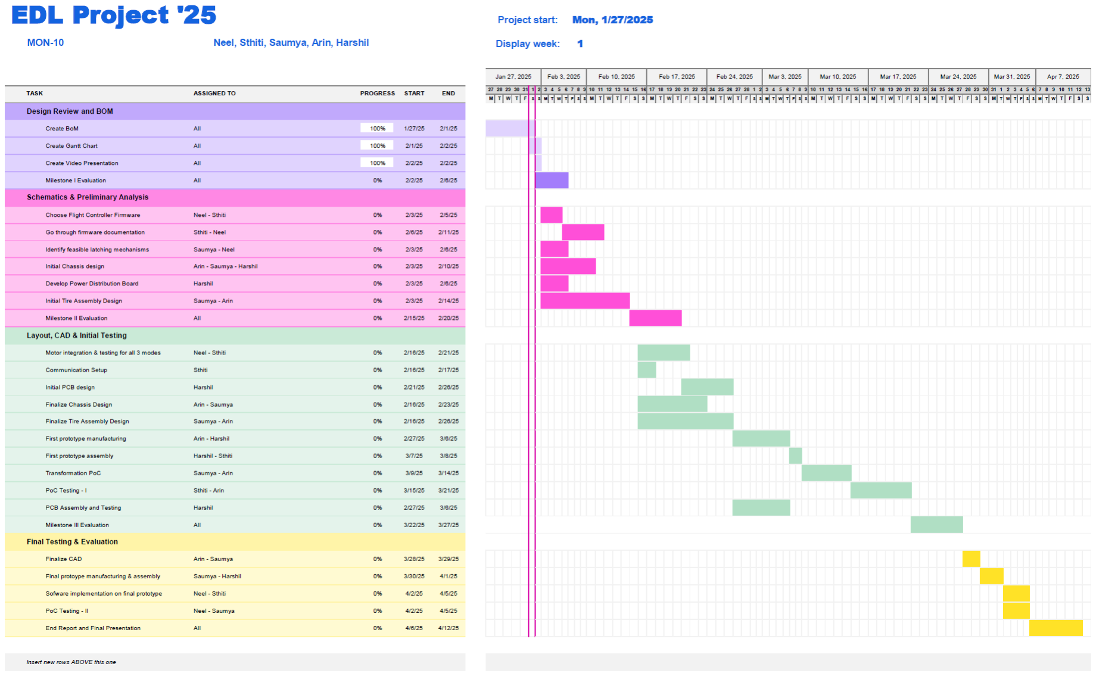
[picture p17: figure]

Bill of Materials

Risks and Mitigation strategies

- Weight: The bot must be lightweight. We have eliminated

redundant components and sought lighter alternatives wherever possible.
- Morphing: The transition between modes should be smooth,

especially from aerial to ground mode. We will perform multiple iterations and simulations.
- Control: Operating both modes using a single µcontroller

increases the complexity of coding, testing, and debugging.
- Rigidity: Since toys often endure rough handling, the

design/material chosen must be sturdy enough.
- High Current Flow: Motor stalling may result in excessive

current. We are considering current limiter and other protection mechanisms to prevent this.

Deliverables

To create an Automated Multi-Modal Mobile Morphobot

- Automated: The robot can transform from ground mode to

aerial mode and vice-versa without manual intervention.
- Multi-modal: Capable of multiple modes of operation:

Ground and Aerial, with scope for more.
- Morphobot: The robot morphs i.e. it transforms from one

mode to another without using extra hardware.

## Thank you!

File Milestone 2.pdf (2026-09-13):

## EE344: Milestone 2

MON - 10
Arin Weling, Harshil Singla, Saumya Shah, Sthiti Padhi, Neel Rambhia

Indian Institute of Technology Bombay

Project Description

Auto-transforming Robot

- To build a multi-modal robot which transforms on user’s

indication.


Figure 1: Caltech M4

Milestone 1 Summary

Design Choices:
- Chose SpeedyBee as the main and flight controller.
- Radiomaster for RC control.
Technical Details:
- Weight and power constraints defined (3 kg max, 4S battery).
- BLDC motors selected for drone mode (750 gf thrust per motor).
- High-torque servos for morphing (35 kgcm torque).
Mechanical Structure:
- Chassis dimensions (planned): 28x8 (ground mode), 28x28 (drone mode)
- Material considerations: lightweight, durable (e.g. carbon fiber) Risks and Mitigation:
- Addressed weight, morphing mechanism, control complexity, rigidity, and high current flow.

Feedback Received

Milestone I review:
- Decide on the material to be used for chassis manufacturing.
- Get an overall cost estimate, accounting for mechanical

components.

Problems analysed by us:
- M4 mechanical assembly exceeds weight constraints.
- Chosen IC had inadequate parameters based on simulations

Addressing the issues:
- The material will be decided post-milestone II review.
- Our budget has been capped at INR 70,000.
- Modified the tyre assembly to satisfy weight constraints.
- Verified calculations and found suitable replacement IC.

Project Management Plan and Documentation

Progress

- All tasks allocated in milestone II have been completed.
- PCB has been sent to fabrication after verifying.
- Further work has been started in terms of mechanical design

for next milestone.

Management Plan
- Group members have been divided into various subsystems.
- Each group member is responsible for a specific task.
- Flexible task scheduling among subsystem members.
- Critical tasks performed by inter-subsystem groups.

All progress has been documented in OneNote with separate
sections for different subsystems. | 5/32

Gantt Chart Updates

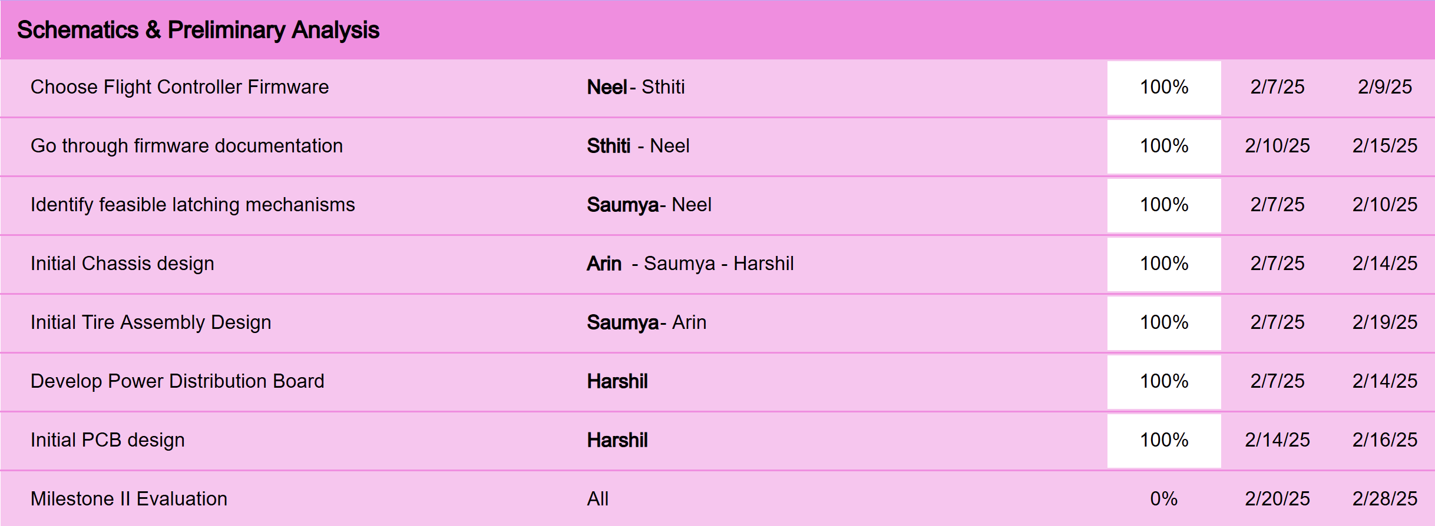
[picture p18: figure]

Figure 2: Updated Gantt Chart

Task 1

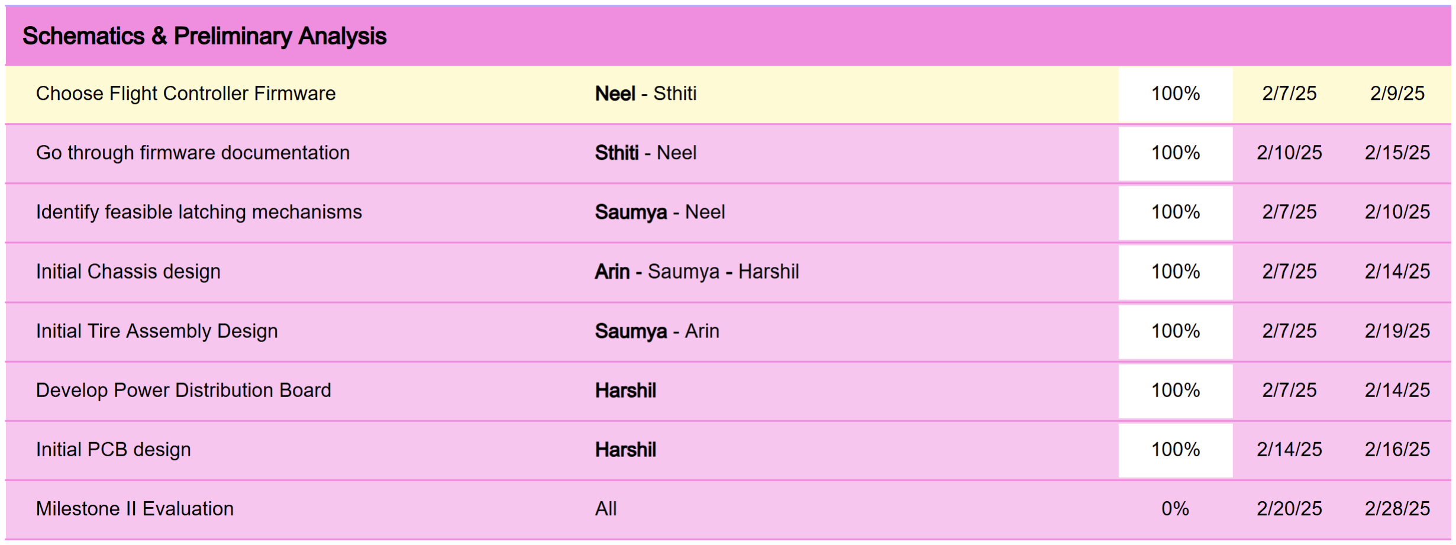
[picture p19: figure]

Figure 3: Task 1

Choosing Flight Controller Firmware

Available Firmware

- Betaflight: Widely used for racing drones and multirotors,

known for its performance and customization options.
- iNav: Suitable for GPS navigation and waypoint missions.
- Ardupilot: A versatile and feature-rich firmware that supports

various types of aircraft.

Ardupilot turned out to be the optimal choice, as it is extremely well-documented and is compatible with a wide range of frames and devices. Being one of the most widely accepted open-source firmware for quadrotors, Ardupilot increases our chances of successful execution.

Task 2

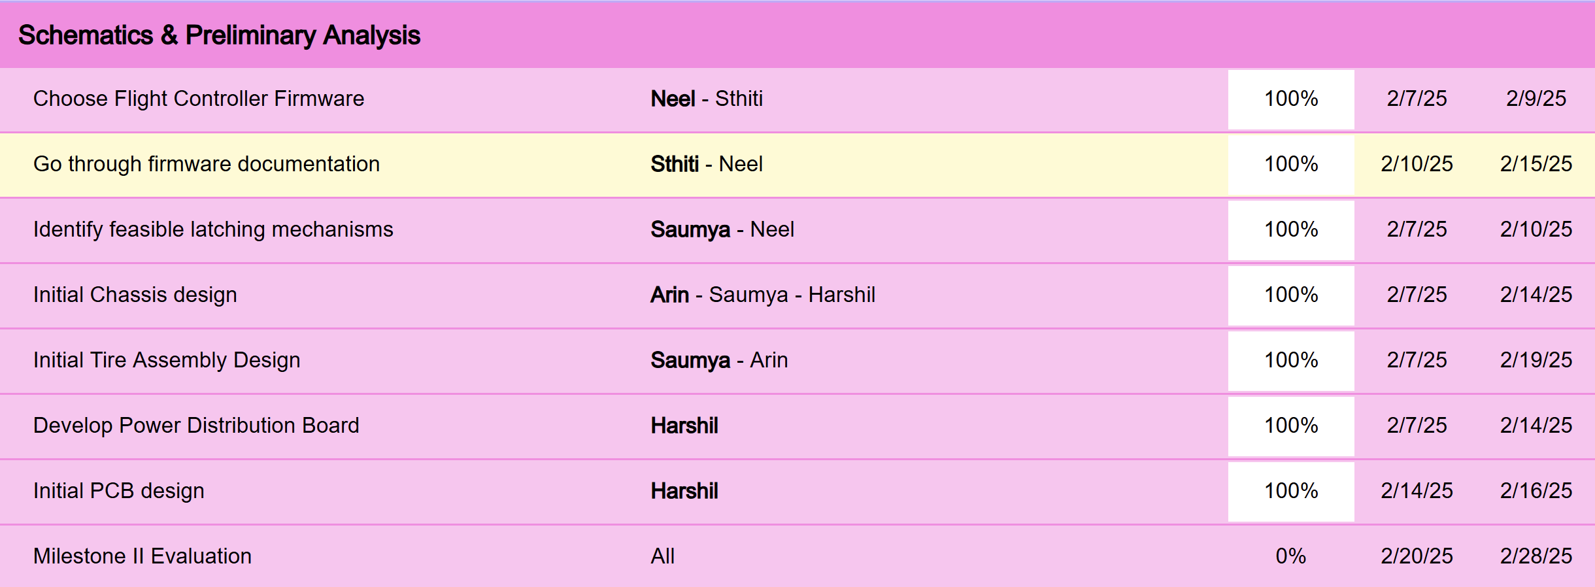
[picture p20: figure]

Figure 4: Task 2

Going through firmware documentation

- Referred and explored the Ardupilot firmware codebase.
- Identified modes of drone operation - Aero, Stabilized, Loiter,

Turtle, etc. We will use Stabilized mode for our drone.
- Current plan for integration with drone mode involves creation

of new custom modes for ground operation and morphing.
- Successfully tested BLDC motors through Ardupilot using the

Mission Planner software (shown in video).
- Simulation for aerial modes explored on Mission Planner.

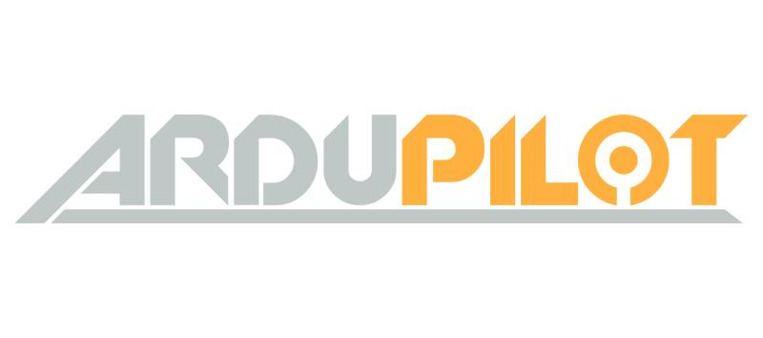
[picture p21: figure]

Task 3

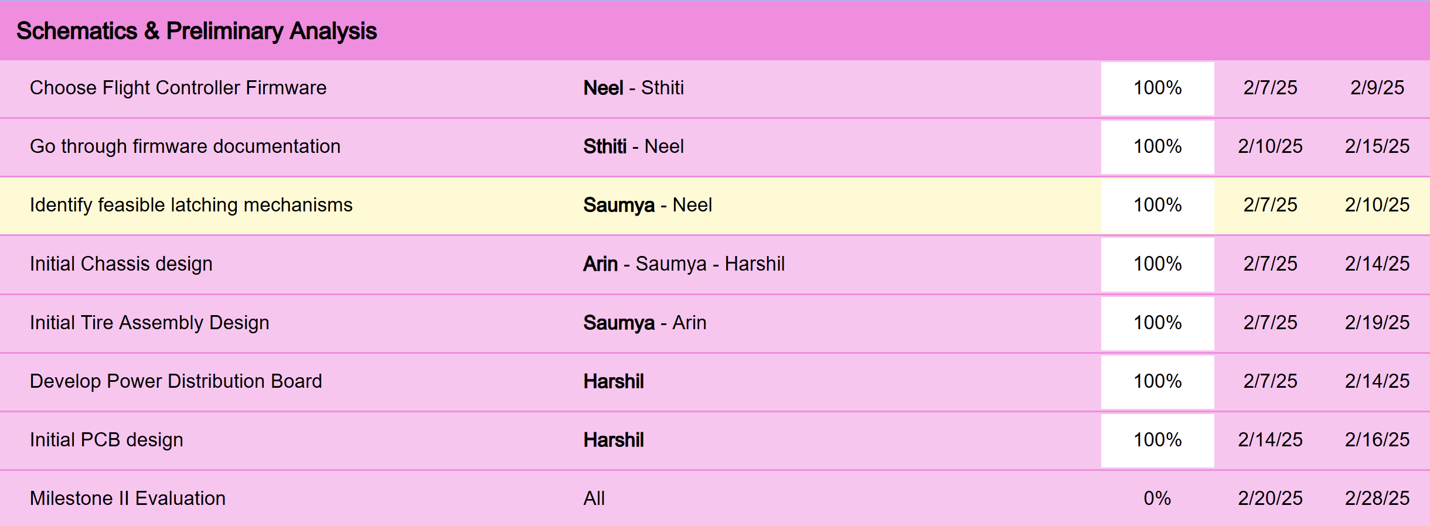
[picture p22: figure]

Figure 5: Task 3

Identify feasible Latching Mechanisms

Mechanism: Push-Push
The latching mechanism locks the arm at a 90◦
servo rotation.
Upon receiving a transform command, the servo briefly pushes the arm up to unlock it, then lowers it to 0◦
, completing the
transition to drive mode.

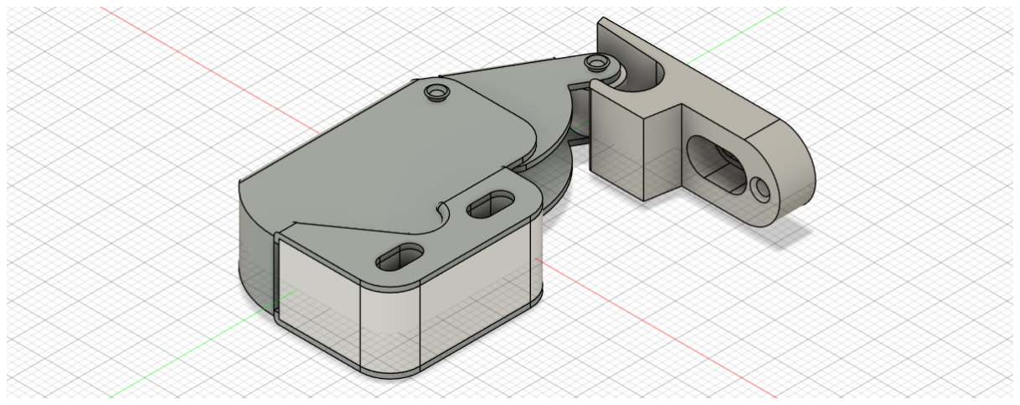
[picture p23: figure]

Figure 6: CAD model of a push-push latch

Task 4

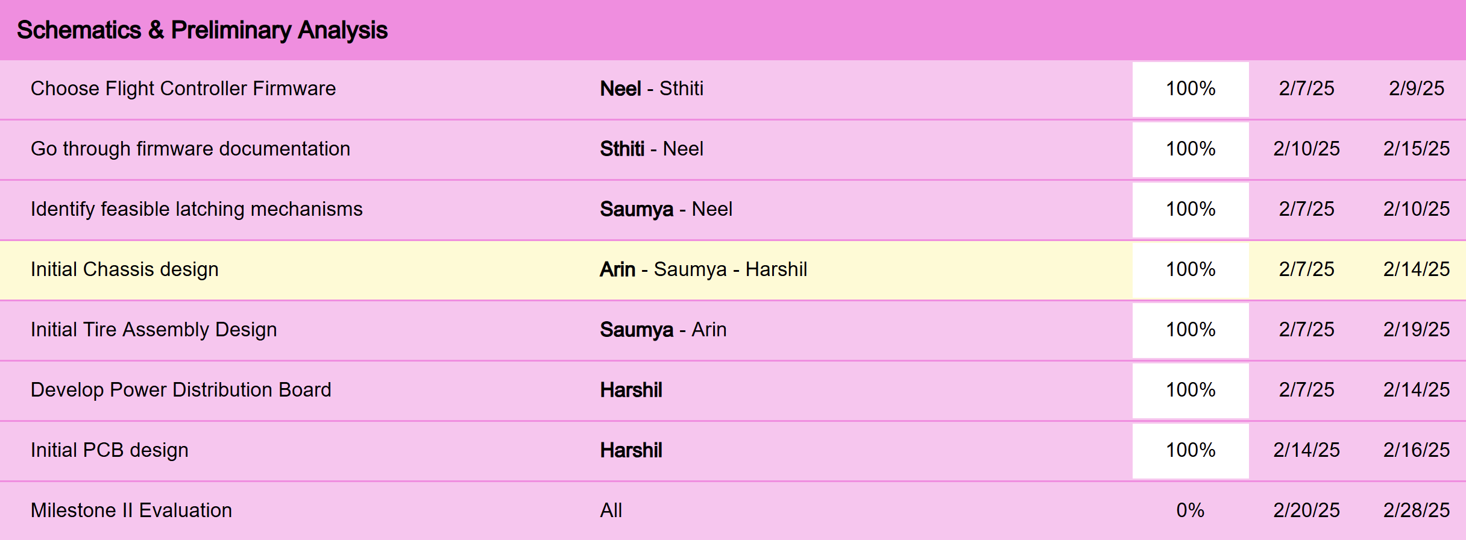
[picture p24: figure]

Figure 7: Task 4

Initial Chassis Assembly design


Figure 8: CAD Model of Drive Mode

Initial Chassis Assembly design


Figure 9: CAD Model of Drone Mode

Initial Chassis Assembly design

- The chassis dimensions have been optimized to maintain a

square shape in drone mode for effective control.
- A battery compartment has been designed such that the

centre of mass of the bot which will majorly be decided by the battery will lie symmetrically to ensure stability.
- All major electrical components have been carefully placed

according to their uses.
- The chassis dimensions are 25.07 cm x 8 cm x 8cm.

Task 5


Figure 10: Task 5

Initial Tire Assembly design


Figure 11: CAD Model of Wheel Assembly

Initial Tire Assembly Design

- Unlike the M4, the propeller and the wheel are placed on

opposite sides to reduce the weight cost of bearings.
- The BLDC motor is placed inside the shaft of the wheel, a

hollow extension allows for securely connecting the motor to the controller.
- The wheel is actuated using an N20 DC motor through a gear

mechanism; our calculations show a max. speed of 12RPM (10cm/sec) in drive mode.

- An L-shaped structure connected to a servo motor acts as our

transforming mechanism, allowing for a sleek chassis structure while maintaining a symmetrical drone frame.

Task 6


Figure 12: Task 6

Power Distribution PCB

- Task 6 and 7 have not only been completed, but exceeded.
- The Power Distribution Board has been designed using the

LMR14050 Buck Regulator IC.
- Schematic for one IC and subsequently the overall circuit

including 2 Buck IC’s, external connections, and test points has been completed.
- PCB layout according to manufacturing constraints has been

completed. Board dimensions are 48mm x 40mm.
- The board has been sent for manufacturing to PCB Power.

Technical Design: Buck Schematic


Figure 13: Buck Schematic

Technical Design: Overall Schematic


Figure 14: Overall Schematic

Technical Design: Board Layout


Figure 15: Board Layout

Calculations and Analyses

- Input Voltage: 14.8V
- Output Voltage: 7.4V
- Maximum Output Current: 3.8A
- Transient Response: 5%
- Soft-Start Time: 5ms

Calculations and Analyses

RFBT = 160kΩ, RFBB = 18kΩ

Choosing switching frequency f = 750 kHz:

Lmin = 3.24µH

Final selection:

L = 4.7µH (available from WEL)

Calculations and Analyses

- RT = 33kΩ ⇒ f = 732kHz
- A Schottky diode rated for 5 − 6A is selected.
- Input Capacitor is 10µF (35V) and 0.1µF for high-frequency

filtering.
- Output Capacitor has two 100uF capacitors.
- Bootstrap capacitor is 0.1uF (given in datasheet)

Circuit Diagram: SpeedyBee Connections


Figure 16: Connections to SpeedyBee F405 V4. Left: Front side, Right: Back side

Block Diagram


Figure 17: Overall Block Diagram

Testing Plans

Preliminary:
- Testing of BLDC motors using SpeedyBee through Ardupilot

Intermediate:
- Control the 3 sets of motors concurrently using SpeedyBee
- Perform simulations on CAD Assembly model
- Proof-of-Concept testing of initial prototype
- Testing functionality and outputs of PCB

Final:
- Comprehensive testing of deliverables on the final prototype.
- Estimate performance metrics of our final product such as

ground speed, morphing time, etc.

Preliminary Testing Results

- Video shows the successful testing of the BLDC motor with

SpeedyBee. We have started developing the Drive and Morph modes.
- Once the RC Modules are acquired, we will sync those

commands to that of the motors.

Thinking ahead...

- Software: Major work will include the creation of custom

modes for ground and morphing operations in order to control the required motors as well as the integration of RC modules for manual control.
- PCB Testing: A simple PCB testing plan has been created

(in OneNote documentation) and will be followed after manufacturing of PCB.
- Engineering Design: Moving ahead, we plan to perform

extensive simulations on our CAD models while also manufacturing an initial prototype to test for faults and further refine our design.

## Thank you!

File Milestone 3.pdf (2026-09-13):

## EE344: Milestone 3

MON - 10
Arin Weling, Harshil Singla, Saumya Shah, Sthiti Padhi, Neel Rambhia

Indian Institute of Technology Bombay

Project Description

Auto-transforming Robot

- To build a multi-modal robot which transforms on user’s

indication.


Figure 1: Caltech M4

Feedback Received

Milestone II review:
- Make micro-deadlines to complete subparts before assembly.
- Acquire materials for mechanical parts so that they can be

manufactured on short notice.

Problems analysed by us:
- Multiple iterations are required to ensure a well-fitting

prototype with clearance
- Need for simpler GUI working with minimal firmware changes

in flight controller software in testing.

Addressing the issues:
- We performed three iterations of manufacturing for assembly.
- Switched from Ardupilot to iNAV testing with less-code

modification.

Gantt Chart Updates


Figure 2: Updated Gantt Chart

Task 1


Figure 3: Task 1

Individual Testing of all Modes

- We have individually done testing for all 3 modes - drive,

drone, and transformation.
- Drive mode: All 4 DC motors are working by interfacing using

the L298N.
- Drone mode: All 4 BLDC motors are working through the

SpeedyBee ESC.
- Transformation: All 4 servo motors are rotating as expected

to transform from drive to drone.
- All tests were done by sending commands using the RC

controller to SpeedyBee.

Task 2


Figure 4: Task 2

Changing Flight Controller Firmware

Available Firmware
iNav: We have switched to INAV for testing out the mechanical assembly. INAV-configurator as a GUI allows easy integration of changing the servo outputs for dc motors and servo transformations. Compared to Ardupilot where we had modified the firmware, we only modified the config files in the firmware leading to easy integration.
- We have tested RC connections with INAV
- We have sent command via joystick to test transform and

drive ability.
- We are working to suitably modify the code to fit our use case

and deal with edge cases.

Task 3


Figure 5: Task 3

PCB Schematic


Figure 6: Overall Schematic

PCB Order Form


Figure 7: Reviewed and Filled

PCB Readiness


Figure 8: Soldered PCB | 12/35

PCB Testing

- The Power Distribution Board has been designed using the

LMR14050 Buck Regulator IC.
- Schematic for one IC and subsequently the overall circuit

including 2 Buck IC’s, external connections, and test points has been completed.
- PCB layout according to manufacturing constraints has been

completed. Board dimensions are 48mm x 40mm.
- The board has been received and tested, it is giving the

correct output and driving Servo motor successfully.

Task 4


Figure 9: Task 4

Chassis Assembly Design


Figure 10: CAD Model-Drive | Figure 11: CAD Model-Drone

Improvements in Design:

- Finger joints used instead of the angle brackets.
- Battery compartment designed to be placed beneath

COM. Slotting done to keep battery stable during
flight.
- Plates have been added to the 5th and 6th side for
stability. | 15/35

Chassis Assembly


Figure 12: Assembly-first version

Final Assembled Chassis

Figure 13: Assembled Chassis

Chassis Assembly

- Side plates and upper plate and lower support have been laser

cut. On finding clearance issues for servo motors on side plates, they have been re-manufactured.
- Battery compartment has been manufactured as first

iteration. Finger joints are used to join individual parts. (Angle brackets give inaccurate measure, tape was used for rudimentary version)

- The fifth and sixth sides were also added to make the entire

chassis stable.
- Motors are integrated and speedybee is fixed on places, final

wiring for product finish remains.
- Model chassis dimensions are 25.4 cm x 8 cm x 8cm.

Task 5


Figure 14: Task 5

Tire Assembly


Figure 15: CAD Model of


Wheel Assembly | Figure 16: Wheel Assembly -
| First version
- The video link for tire assembly working driven by DC

motor and gear set-up. This is the first version. (https://drive.google.com/file/d/11z_ywImVJwMVHcvrbXsjO7rD90DIEmKA/view?usp=sharing)
- The final version with modified leg design and

assembled drive mode can be viewed here. (https://drive.google.com/file/d/11z_ywImVJwMVHcvrbXsjO7rD90DIEmKA/view?usp=sharing)

Tire Assembly

- Design of tire assembly was modified after first prototype to

fit servo horn hold and to fix DC motor.
- We manufactured (3D printed) the wheel twice to reduce

weight and increase clearance between wheel and chassis.
- The wheel was 3D-printed at 20% infill to reduce weight of

the model.
- The leg is designed in without wire compartment in the latest

iteration for better integration.
- The leg is attached to servo horn and rotates on command to

servo. This a first version transforming video. (https://drive.google.com/file/d/1XVSCFOOEE3vuQkgRGwyFr29k7PECtEjC/view?usp=sharing)

Task 6


Figure 17: Task 6

Manufacturing Process

- The parts of the chassis (top plate, bottom plate and side

plates) have been laser cut for precision.
- The first iteration of wheels were 3D printed, the next

iteration was laser cut.
- The gears were also laser cut for precise spokes.
- The parts of leg assembly were 3D printed.


Figure 18: Laser cutting on acrylic sheet

Task 7


Figure 19: Task 7

Final Assembled PoC


Figure 20: Final Assembled PoC

Task 8


Figure 21: Task 8

Trasformation

- Video shows the prototype of morphobot, commands are sent

from RC module and executed - transformation mode.
- The servo motors are given commands from the RC controller

and rotate 90 degrees as shown.
- [Video Link] (https://drive.google.com/file/d/1XVSCFOOEE3vuQkgRGwyFr29k7PECtEjC/view?usp=drive_link)

Task 9 - Demo


Figure 22: Updated Gantt Chart

Proof of Concept

- Video shows the prototype of morphobot, commands are sent

from RC module and executed - drive mode.
- Mechanically, we have identified and improved upon tire

assembly and design.
- We have tested BLDC motors, drone mode will be tested after

model is finalized to avoid risking crashes due to mechanical malfunction.
- [Video Link] (https://youtu.be/f1GSzysrYtw?si=lYR7eUmgE5Z5kRDF)

Circuit Diagram: SpeedyBee Connections


Figure 23: Connections to SpeedyBee F405 V4. Left: Front side, Right: Back side

Block Diagram


Figure 24: Overall Block Diagram

Work Distribution


Figure 25: Work responsibility allocation

Testing Plans

Mechanical Assembly:

- After testing Drive and Drone mode in use, suitable end-stage

adjustments to be made.
- Final prototype to be manufactured after above design

decisions.

Software Integration:

- Smooth control of bot as drone and as rover, and smooth

transformation.
- Testing time of operation (time of flight) and seamless

communication.

Testing Plans

Electrical Final Checkouts:

- All electrical connections have been made and they are

working properly.
- Final tests will be run again with greater stress scenarios

(such as running on an almost discharged battery).

- Electrical connections will checked and then isolated and

firmly connected using electrical tape.

Project Management Plan for Final Demo

Progress

- All tasks allocated in milestone III have been completed.
- PCB has been soldered and tested.
- Mechanical assembly has been done after multiple iterations.

Management Plan

- Debugging and Testing performed in at least groups of two.
- Ideally, one person from software and one from mechanical to

be present.
- Each member aware of all design decisions and working.

All progress has been documented in OneNote and separate
markers for subsystems. | 35/35

## Thank you!

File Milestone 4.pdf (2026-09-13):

S.N.A.S.H.

- Sthiti Padhi (22b3921)
- Neel Rambhia (22b1298)
- Arin Weling (22b1230)
- Saumya Shah (22b1238)
- Harshil Singla (22b1260)


An Automated Multimodal Mobile MorphoBot which combines driving and flying for search and rescue, payload delivery, and site inspections, offering extended battery life and multi-terrain adaptability for efficient operations.

## The Auto-Transforming Robot (MON-10)

# Status of project

Key specifications and requirements proposed at beginning of semester | Status at end of semester | Remarks/Justification
Automated | Complete | The bot can transform without manual intervention
Multimodal | Complete | Drone and Drive modes demonstrated successfully
Weight < 3kg | Complete | The total weight is 2kg
Drive speed > 0.5m/s | Complete | The maximum speed of the bot is close to 0.5m/s
Battery Life > 15 mins | Complete | Flight time ~2 minutes Drive time ~15 minutes
Morph Time < 1 minute | Complete | Morph time is ~4 seconds

# Photographs of final prototype


Drive Mode | Morph Mode | Drone Mode

# Internal and External Components


## Wheel Assembly

## PCB

# Some Amazing Photos!!


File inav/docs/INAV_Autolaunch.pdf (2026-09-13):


This manual and the contents within are the intellectual property of the INAV Fixed Wing Group. © INAV Fixed Wing Group 2019, All rights reserved.

# SET UP AUTOLAUNCH CORRECTLY

by Marc Hoffmann
Editing and color commentary by Steve Schlesinger

TABLE OF CONTENT

INTRODUCTION

The INAV Autolaunch mode is a very useful feature for all kind of planes that need to be hand-launched. With this helpful feature it is much easier to throw-launch a plane and much safer than throwing a plane with a propeller spinning at 10k rpm, especially if you have a pusher plane. In general, the Autolaunch feature works out of box for most planes. Just enable the mode and you are good to go. But you’ll have to have a setup with a perfect thrust to weight ratio, and you will need to do a perfect throw in the right angle and with good speed and hopefully you’ll have a little bit of luck. If your planes are too important to you to trust them to pure luck, thankfully we’ve got your back. In this guide we will explain the launch mode in detail and help to show you how to find better settings for your plane and make Autolaunch as easy as throwing a paper plane - except of the fact, that your plane will keep flying!

AUTOLAUNCH SETTINGS

The first thing to know: The relevant Autolaunch settings are not (yet) accessible through the configurator GUI. You need to do the necessary changes in the CLI mode. There are an infinite number of possible combinations for
these settings that all need to work together to make your plane launch well. But if you understand each option and how to decide the best values for your needs, it makes life much easier. In the following table you will find all the essential options and how to set them with some additional functions, to make Autolaunch better tailored to your specific needs.

The thing that is crucial is that you have a plane that flies stable. We’ll be talking more about this in future articles. In the meantime, the rule of thumb is that you want a plane that can fly well in manual and in angle modes with no trims. You also want a plane that doesn’t freak out’ because the PIFF values are set too high. This means you’ll need to get your plane to a point where it’s ready for the Autolaunch.

If you decide to use Autolaunch for your maiden (not recommended), make sure you select a good close preset in the "Preset" Tab that closely fits your plane and select low PIFF values. Especially for smaller wings these should be maxed at PIFF 8, 5, 50 for pitch and roll and even lower on yaw (can be 5,0,50). We don't really need an I gain on yaw.

MAIN SETTINGS

CLI name and default value | Description
nav_fw_launch_max_angle = 45 | Max throwing angle that is allowed to be accepted as a valid launch throw
nav_fw_launch_thr = 1700 | Motor throttle value during launch procedure
nav_fw_launch_idle_thr = 1000 | Motor throttle value when armed and before launch
nav_fw_launch_motor_delay = 500 | Wait time after throw, before motor goes to launch throttle power
nav_fw_launch_spinup_time = 100 | Time for incrementally increase the throttle from idle to launch throttle to avoid motor stall
nav_fw_launch_climb_angle = 18 | Angle to climb at during launch sequence

HOW TO CHOOSE EACH SETTING

NAV_FW_LAUNCH_MAX_ANGLE

The launch angle depends on the way you launch your plane. If you have a standard fixed wing like a trainer (5 channel) or a Talon style, you probably launch it with one hand under the fuselage and throw it like a big paper plane. In this case the default angle of 45° is totally fine to avoid accidental launch detection when carrying the plane after arming it. For flying wings, you launch with a wing throw (not recommended because Autolaunch could flip it and crash into ground with full throttle) this is fine too. If you decide to do an over-head launch (by throwing it backwards over your head) you need to set this value much higher. It is fine to select 180 in this case.

NAV_FW_LAUNCH_THR

The launch throttle is mostly depending on 2 factors: The thrust to weight ratio of your plane and the capabilities of your hardware (battery, esc and motor power capabilities). We recommend a value where your plane is close to over, when you hold it in our hand nose up and throttle up manually but would not climb if you would let it go (of course do not do that!). If the plane is very big and has a low thrust ratio, set this to 2000. Also check the current that is needed to obtain the selected throttle value on the bench. Your battery, ESC and motor need to tolerate this amount of throttle for about 10s without overheating, to avoid any damage. (See ‘Determining throttle setting’ for more information on this topic.)

NAV_FW_LAUNCH_IDLE_THR

By default, the idle throttle is set to 1000 which means no throttle. This is totally fine on standard props. There are 3 scenarios where you can or even should select a higher value to keep the motor already spinning before you throw it.

Scenario 1: You have a very low thrust to weight ratio, or a very heavy plane and you needs an extra push when throwing to gain speed faster and avoid a stall or height loss. A Good value here would be 1200-1400 depending on your motor power. Be aware, that the motor will spin at relative high speed as soon as you raise the throttle after arming!!!

Scenario 2: You are using a folding propeller. It can be very stressful for your motor, props and even fuselage if a folding propeller is spinning instantly to 100% power if it is folded. So, you can use a low value like 1100 to make sure the prop is open and in balance before launch.

Scenario 3: If you really want to launch a wing b a wing throw, it makes sense to give it a high idle throttle value. This avoids a strong yaw spin when throwing the wing and makes your launch more stable. Half to two thirds of the launch throttle value is recommended in this case. An example, if your launch throttle is 1700 this should be set to 1350-1450.

We recommend to keep Motor Stop feature enabled to avoid motor spin on arm. It will spin at idle throttle as soon as you rise the throttle stick on the remote.

NAV_FW_LAUNCH_MOTOR_DELAY

This delay brings extra security, especially for pusher planes. By default, this is set to 500ms but especially for smaller planes, that quickly lose speed because of low weight, this time may be too long, and the plane will hit the ground before the motor has full power (which would suck). Therefore, you should lower this value. We recommend a value of 200ms. For pull-prop planes (nose propeller) you can even set this to zero. Do not set this to zero on pusher planes because the propeller could hit your hand with full speed (unless you wing toss, in which case this is fine).

NAV_FW_LAUNCH_SPINUP_TIME

As soon as the launch is detected and after waiting for the motor delay time, the FC will power up the motor. By default, the throttle will rise smoothly from idle throttle to launch throttle in a timeframe of 100ms. This is important to avoid motor stall, especially for bigger props and folding props. For planes with 8-10-inch props we recommend even 200ms and more on larger propellers. You can test this on the bench to make sure the motor gets full power without stuttering (but be careful).

NAV_FW_LAUNCH_CLIMB_ANGLE

After launch throttle, this is the most important value and it depends on a multitude of factors. Motor Power, weight of the plane, throw speed and possible lift. Big planes or motor glider with a very high lift ratio and low thrust, should keep a low climb angle like the default 18°. Also, small planes with a low thrust to weight ratio should keep a lower angle but not below 20° because they can quickly loose speed while motor goes to full power. Then the FC need to pitch harder up to gain back height. Also, a bit higher P-Gain in PIFF controller can help to get a quicker climb angle. We recommend 25-30° but make sure the plane can sustain speed at this climb angle without stalling. If you have a highspeed setup and a lot of power, select a very steep climb angle.

During the first second or two, while the plane is accelerating, this causes backwards G-forces that could make the FC “think” it is already climbing and can cause even a nose down in some conditions. Therefore, the thrust for launch should never be higher than the plane could hover on its propeller. Better slightly lower to get a quick and correct climb angle.

OPTIONAL SETTINGS

CLI name and default value | Description
set nav_fw_launch_accel = 1863 | Needed G-Force when throwing to detect launch
set nav_fw_launch_detect_time = 40 | Time in ms the launch acceleration needs to be exceeded to accept the launch
set nav_fw_launch_min_time = 0 | Time to ignore any stick input after launch sequence has started
set nav_fw_launch_timeout = 5000 | Time for the launch sequence to run. After that the Plane will switch to the actual active flight mode.

HOW TO CHOOSE EACH SETTING

NAV_FW_LAUNCH_ACCEL

It is not necessary to change this value. By default, this means, the FC need to detect a force of 1.8G to accept the launch throw. For big and heavy planes, this can be lowered because they are harder to throw. But be careful, because launch detection will be more sensitive and accidently launch activation could happen.

NAV_FW_LAUNCH_DETECT_TIME

This should not be changed for throw launches. It is a good value to get a reliable launch detection. For a catapult launch you can set this a bit higher, depending on the length of the catapult. But it is more useful to rise the motor delay time than the detect time.

NAV_FW_LAUNCH_MIN_TIME

If you launch your plane while you have your remote in the other hand, it can be safe to set some delay here. Especially on some remotes with very sensitive sticks, this can avoid accidental Autolaunch aborts when the remote gets a shake during the throw. We recommend to not go above 2000 (two seconds) to still be able to gain control and abort a launch as soon as possible if needed. This means for a full two seconds you will not be able to control your plane.

NAV_FW_LAUNCH_TIMEOUT

Sometimes the default 5000 (five seconds) can be a bit short to take the remote, put on your FPV goggles and take a seat in a camping chair, crack open a brewski, open some Dorritos. So it is always a good idea to rise this value up a bit. In theory this can be set up to 60s (value 60000) but then the plane will fly far away. But hey, this is a good time to wonder if you have your RTH set to first launch? You ask Marc to tell you a funny story about this topic. Set a value that is comfortable for you.

NAV_FW_LAUNCH_MAX_ALTITUDE

By default, this value is disabled. But if you want the plane to always climb to a specific height it makes sense to put a useful value here (in cm). The plane will then abort the launch sequence as soon as the set height, or as soon as the timeout is reached. To make sure the height is reached, you need to set launch time high enough, especially at flat climb angles. But we recommend to not disable launch timeout. Otherwise this can cause a flyaway if the barometer or GPS height fails, because during launch, failsafe RTH is ignored due to a bug in INAV 2.0 and 2.1. (will likely be fixed in 2.2).

DETERMINING THROTTLE SETTING

The first thing is that throttle settings influence thrust but there isn’t a one-to-one correlation between throttle setting and thrust. What this means is that the best throttle setting for your plane will be plane specific. We would love to tell you a value at this point that you could use for all your planes. You will need to perform this test for each plane.

When you look on your receiver tab in the INAV configurator, you will notice that as you move the throttle up and down the values change. In a perfect world the very bottom of the throttle range is 1000. 1000 represents ”no throttle.” In reality it may be something like 980. If you haven’t calibrated your receiver in a while this may be the best time to do it. it’s common for the sticks to be of a bit, and it won’t affect performance of the plane. But for the rest of this example, we’ll talk as though your throttle was perfectly calibrated. This would mean that 1000 is off and 2000 would be full throttle. 1500 would be half throttle. Thus 1250 would be quarter throttle and 1750 would be ¾ throttle. If this doesn’t make sense, go back and read this again. You will need to guestimate a number and it should be fairly close to accurate for best performance.

Hold your plane straight up with one hand and with the other you’ll need to work your throttle. You may want to do this outside. With the throttle off you will feel the full weight of the plane in your hand. As you fire up the throttle the plane will become lighter. When it feels like it’s just about ready to fly out of your hand, note where the throttle position is. If you're at half throttle the number would be 1500. If you have a woefully underpowered plane the value may be closer to 2000. Use this value for nav_fw_launch_thr.

IS YOUR PLANE READY?

One of the most important assumptions we make about Nav Autolaunch is that your plane is setup well. What you need to keep in mind is that for a short period of time your plane is flying by itself. So, let’s use some common sense. First of all, go somewhere that you’re able to launch the plane that is away from people and property. Sometimes things go wrong, and we just want to be sure that we keep your risk exposure low.

The second thing is, if your plane is flying wonky, don’t play with this mode. You are going to want to focus your efforts on getting your plane flying well. A flight controller helps a good plane fly better, but it can only do so much for a plane that isn’t set up well. We’ll be covering this topic more in the future, but the gist is to make certain your plane can fly well in the manual mode without trims. Then use servo auto trim and autotune to make certain your plane is flying well in the stabilized modes. If the plane is pitching down in stabilized modes, you can add more ‘nose up’ with a positive pitch value in the configurator tab under pitch. You want to add low values like 1 or 2. However a good autotrim should fix this.

The last thing is that you’ll want to make certain that you can bring the plane back to you. If your radio has a range of 1km and your plane is flying faster than 60km/h you will fly out of radio range before you’re ready to fly. Hopefully your NAV RTH is set right. You can also add Nav RTH to NAV Autolaunch so that that the plane goes into its NAV RTH routine after the launch is complete. This can allow you more time to get your goggles on. You will want to test NAV RTH before you enable this feature.

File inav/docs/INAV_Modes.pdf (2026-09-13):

INAV Modes – How they work and how to set up

by, Marc Hoffman
Editing and color commentary by Steve Schlesinger and Marco Lau

Know your modes!

The goal of putting a flight controller in your plane is to allow your planes to do things that weren’t possible just a few years ago. Words cannot describe the feeling the first time you flip a switch and your plane comes back to you. What used to be pure science fiction is now a very affordable reality. And this is all just the start of what’s to come.

And yet, one criticism of INAV is that it’s perhaps too powerful. It’s capable of so many things, and yet what you don’t know can hurt you. When you installed your flight controller you wanted to use all 16 channels and install all the modes all at once. It certainly easier to do this than to go back over and over again and update INAV. But keep in mind that some of these modes surrender some if not all control of the plane. Thus, you can very realistically watch your plane fly away never to return. With this guide you should be able to figure out what all the modes are capable of doing. It’s best to explore them one at a time. There may be certain modes you’ll never use, such as camstab. So, be selective in what you wish to include. And no, you don’t need to use every switch on your radio to enjoy INAV.

INAV in a fixed wing plane brings a multitude of possibilities. It starts with simple in-flight stabilization which keeps your plane flying like it is on rails. Wind gusts are dealt with in real time and further enhance the flying experience. The ultimate INAV experience are fully autonomous flights, where your plane can fly complete missions over big distances, like a real military drone. It is amazing how far such simple technology in this hobby has been developed but all these features need some knowledge to be able to use correctly.

In this guide, we will explore in detail the different modes and features of INAV and explain how to correctly set them up and how they work. First, we will explain, how every mode works by itself and in the second part, we will explain their dependencies and preconditions.

Part One – Main Flight Modes. The modes in this table cannot be combined with each other:

Mode | Description
STABILIZED (RATE MODE) | This is the default mode of INAV. This is always active if you do not add other flight mode (s). This is similar to the Acro mode on multicopters. INAV will always try to keep the current attitude of the plane if there is no stick input by the pilot. As in most flight modes, the flight controller takes over the complete control of the servos and the input of the pilot controls how fast the plane has to spin around the specific axis (rate control). The speed of the spin is limited by the rate limit in the software on full stick input. (more on that later in the Tuning Guide)
ANGLE | In angle mode, the control will change from rate control to angle control. The plane will always keep itself level if there is no stick input. If there is stick input for roll or pitch, it will change the angle relative to the stick movement. At maximum stick

| movement, the plane will pitch or roll only as far as set in the firmware. There is no automatic control of height and throttle, so the Pilot still needs to be aware of that. The yaw axis is still in a rate controlled mode and only stabilized.
HORIZON | Horizon mode is very similar to Angle mode. The only difference is, that at a certain amount of stick input, Horizon mode will automatically transition to rate control and allows the pilot to do rolls and loops, but the plane goes back to angle control if the stick is below this threshold.

NAV
CRUISE

This mode needs a working GPS module. In Cruise mode, the plane will completely autonomously keep its course in the air on a straight path. The pilot does not have direct control over yaw and roll but changes the flight course direction via the roll stick. This means that the roll input will have very limited authority. INAV will do all the needed attitude changes by itself to keep the selected course. Also the throttle is controlled automatically by INAV and is depending on the pitch angle. Cruise throttle needs to be set correctly. This will not apply to the height, the plane is flying at. So, pitch is still controlled in angle mode (2D Cruise). See ALTHOLD mode for 3D Cruise. In summary, in this mode no yaw, limited roll and angled pitch input. Throttle override by pilot is optional.
NAV
POSHOLD

With this Mode, you can “park” the plane in the air. It will save the coordinates and height as a center point and try to fly a constant circle around that point. With the yaw stick, the pilot can change the circle direction (if activated). With the pitch stick, the height can be changed. There is no further control possible, while in this mode. POSHOLD needs GPS and barometer to work (without barometer the height will be very unreliable). In summary, in the NAV Poshold, the plane flies in circles. The only two things a pilot can do is change the circle direction and altitude. The Circle size can be configured via CLI.
NAV RTH | Return to home can be one of the most important modes you will ever use. Of course, this needs GPS and Barometer to work. As soon as the pilot ARMs the plane, it will save its GPS position on the Flight Controller. If you ever get in trouble by flying too far away, lose sight or just want to come back from a long-range flight without getting bored staring on the FPV feed, you can enable RTH and the plane will autonomously fly back home. You can control the height of the return with the pitch stick but not the direction. There is also a RTH mode in case of a remote connection loss but this one, behaves slightly different. More on that later.
NAV WP | In WAYPOINT mode it is possible to let the UAV fly nearly complete unattended missions by itself. The pilot can use different applications (INAV Configurator on Windows, MultiWii planner on Linux, INAV Mission Planner on Android, INAV Flight on iOS) to plan waypoints on a map with specific height and upload them to the Flight Controller via USB and also wireless, if you install a Bluetooth or WiFi module. Then you can let the FC automatically fly this mission, as long as you keep in range of your remote. It is not (yet) supported to do missions without control connection. This is an advanced mode, you will want to master the other modes before attempting to work with Nav WP. Your planes should be well trimmed , tuned and calibrated.
MANUAL | The MANUAL control mode is very helpful during the initial tuning phase of the plane. In the case that anything is wrong with your setup, sensor failures, bad PIFF values, unstable flight behavior, you can switch into manual mode, and all automatic stabilization(s) are disabled. The pilot has direct control over the servos and can fly like a normal flight without ANY input from the flight controller. The servo mixing, especially for Flying Wings or V-Tail planes is still done by INAV, so no mixing on the transmitter is necessary. When setting up a new plane the plane should be manually trimmed using the Manual mode so that it can fly well without radio trim.

After explaining, what every main flight mode does, we will now look at the additional modes, that cannot be used standalone but can add additional functionalities to the modes above:

Mode | Description
NAV ALTHOLD | Combine with self-level modes: ANGLE, HORIZON, NAV CRUISE
| This mode will tell the FC to automatically keep its current height in the air. It will only affect the pitch control type of the plane and only works with self- leveling flight modes. While in plain self-level modes, the pilot controls the pitch angle with the stick input directly (see above). If ALTHOLD is added to one of these modes, it switches in climb-rate control. That means, that the pitch stick will only send commands to change the height at a specific rate and INAV will automatically adjust the needed pitch angle and motor thrust (CRUISE only).
| Values that are relevant: nav_manual_climb_rate – value in cm what the maximum climb or descent rate will be on full pitch stick input. If it is set too high, it will be physically limited by nav_fw_climb_angle and airspeed. nav_fw_climb_angle – max climb angle used to sustain requested climb rate. Is limited by max_angle_inclination_pit (Global max pitch angle). If climb angle is set higher, then max_angle_inclination_pit will be the limit to climb. Be careful setting the climb angle, because too high values can cause a stall and in auto modes, this will likely cause a crash.
AIR MODE | Should be permanently enabled as a feature to be active on all relevant modes Combine with: STABILIZE, ANGLE, HORIZON
| AIR MODE keeps the PID (PIFF on fixed wing) controller always active, even when throttle is zero. This is very important for all flight modes with manual throttle control. If this mode is disabled, you will loose stabilization if you go to zero throttle and the plane will behave like in MANUAL mode but much lower control authority. It is highly recommended to permanently enable this mode as a feature in configuration tab.
| No special values to set up
NAV LAUNCH | Combine with: STABILIZE, ANGLE, HORIZON, NAV CRUISE, NAV POSHOLD, NAV RTH
| More information in our Autolaunch manual (https://1drv.ms/w/s!Ar6QsGgoXRgqm_IJPMRWoelddZOsXQ)
SURFACE | Irrelevant on fixed wing
TURN ASSIST | Irrelevant on fixed wing
HEADING HOLD | Irrelevant on fixed wing
HEADFREE | Irrelevant on fixed wing
HEADADJ | Irrelevant on fixed wing

All the main modes have some settings and variables that can or need to be changed, to fit your needs or fit your plane. This will not include tuning values like PIFF Controller. We will explain these in the tuning guide later. All Modes that are lower in the table will also be affected by the values of the modes above.

Mode | Configuration values
| Needed Hardware | Gyro
| roll_rate=20 pitch_rate=20 yaw_rate=20 (only with rudder) | Defines the maximum rates (in 10x degrees/s) the plane can turn on the specific axis. The maximum rates need to be determined before in MANUAL mode (See tuning guide). Can be set via GUI in PID-Tuning Tab
| align_gyro=DEFAULT | Sets the correct board alignment. Need to be correct so pitch, roll and yaw movement detected by the sensor, matches the movement of the plane. Can be set via GUI in Configuration tab in 90° steps and flip.
| align_board_roll=0 align_board_pitch=0 align_board_yaw=0 (only with rudder | Fine tunes board alignment if it is not precisely mounted in 90° steps. It will change the alignment of the board in 0.1° steps. Positive and negative values possible.
| rate_accel_limit_roll_pitch=0 rate_accel_limit_yaw=10000 | With these values, it is possible to limit the acceleration of rotation. For small planes this can be very high (or even disabled) but recommended on bigger planes with more than 1 meter wingspan. Limiting the roll, pitch and yaw acceleration can give you a smoother transition between high rotation rates and still flight (hard stick inputs). Do not set it too low. Start with 5000 for pitch on roll and try to figure out best values slowly. If it is too slow, the plane will become extremely sluggish or uncontrollable.
ANGLE | Needed hardware | accellerometer
| max_angle_inclination_rll=30 0 max_angle_inclination_pit=30 0 | These values determine the maximum angles in ANGLE flight mode. It also limits the overall angle limit for all other flight modes with auto-level functionality.
HORIZON | Needed hardware | accellerometer
| fw_d_level=75 | This value sets the transition point, when Horizon mode will switch from angle control to rate control. A value of 75 means, that a roll stick output of more than 75% to each side will cause a full roll movement like in STABILIZED mode.
NAV CRUISE | Needed hardware | GPS (baro recommended for ALTHOLD)
| nav_fw_cruise_thr=1400 | This is the applied throttle value when in cruise mode. It needs to be high enough to make sure, the plane has enough airspeed to keep a good control authority and does not stall. Rule of thumb: keep the plane at least 30% above stall speed. You can determine the correct throttle in manual flight

STABILIZED
(RATE)

| by doing a stall test and take the stall speed as reference.
nav_fw_allow_manual_thr_in crease=OFF | Turning this on, will allow you to override automatic throttle control in all navigation modes. You cannot go below the automatic throttle value (except with motor stop on zero throttle) but you can rise the throttle manually if needed. If this is activated, you should always keep the throttle stick very low, when in auto mode, if you want to have a slow and efficient flight. If throttle is too high, it could rise the turn radius in navigation modes massively.

nav_fw_min_thr=1200
nav_fw_max_thr=1700

These values set the max and min throttle during all navigation modes, when pitch is controlled automatically. These should be set wisely. On planes with good gliding behavior and low drag, the min throttle can be set lower (do not set it to 1000 when using folding props as throttle reactivation can be too quick for a folder). On fast planes like warbirds or light foamboard planes, this should be kept higher, to avoid speed loss. Max throttle is the most important. This must be high enough to keep air speed when the plane is pitching up. It must be high enough to keep airspeed, when INAV is pitching up to nav_fw_climb_angle. You should test this manually in ANGLE mode and check with OSD or via LOG. More about this in the Tuning guide.
nav_fw_bank_angle=20 nav_fw_climb_angle=20 nav_fw_dive_angle=15 | These are the angles on pitch and roll axis, that are allowed during all autonomous flight modes. These should be set high enough to get acceptable turn rates and climb or dive speed but not too high. If bank angle is set too high, you risk to loose altitude too quick and due to GPS direction delay, the flight will be very sluggish. Climb angle must not be higher than your motor power allows without getting the plane to stall. And dive angle should also not be too high to make sure INAV has enough time to go level again when diving very low and the plane does not get too fast.
nav_fw_pitch2thr=10 | This value determines how much throttle INAV will add or subtract from nav_fw_cruise_thr for every degree of pitch. Example for default values: In level flight the ESC gets 1400 throttle value. When pitching up 15 degrees, INAV will give a throttle value of 1550. With pitch down 20 degrees, it will send 1200 to the ESC. Upper and lower values are limited by min and max throttle (see above). Should be tested in ANGLE mode and should be set to a value, where airspeed keeps the same at every climb and dive angle.

| nav_fw_cruise_yaw_rate=20 | This is the turning rate when applying full roll stick input. Don’t be confused by the yaw. This also applies to Wings and V-Tails. On wings INAV will use bank and yank to change its course but it will also use rudder if available. This should be set higher on smaller planes. The maximum yaw rate depends on the max allowed nav bank angle.
NAV POSHOLD | Needed hardware | GPS (baro recommended for ALTHOLD)
| nav_fw_loiter_radius=5000 | This sets the redius of the loiter circle if the plane is in POSHOLD or RTH LOITER. Default is 5000cm (50m) but should be set higher on bigger planes.
| fw_loiter_direction=RIGHT | This value determines if the final loiter direction will be clockwise (RIGHT) or counter clockwise (LEFT). It is also possible to select the loiter direction manual with the YAW stick. To enable this, set the value to YAW
NAV RTH | We will do a separate Document for RTH and Failsafe settings.
NAV WP | nav_wp_radius=100 | Determines the distance to a set waypoint, to accept it as reached. This must be set higher for FW because it is very unlikely, to hit a waypoint at 100cm precision. 1000-3000cm are good values here, depending how agile your plane is and how far you set the WP apart.
| nav_wp_safe_distance | This is the maximum distance between the Home-Position and the first waypoint. This is a safety value, that avoids accidental flyaway, in case a wrong mission is loaded for a location far away.
MANUAL | manual_rc_expo manual rc_yaw_expo | This value will add an expo for RC inputs in MANUAL mode. You should disable any expo setting in your transmitter and only use INAV setting here.
| manual_pitch_rate manual_roll_rate manual_yaw_rate | With these values you can limit the maximum servo throw in manual mode.

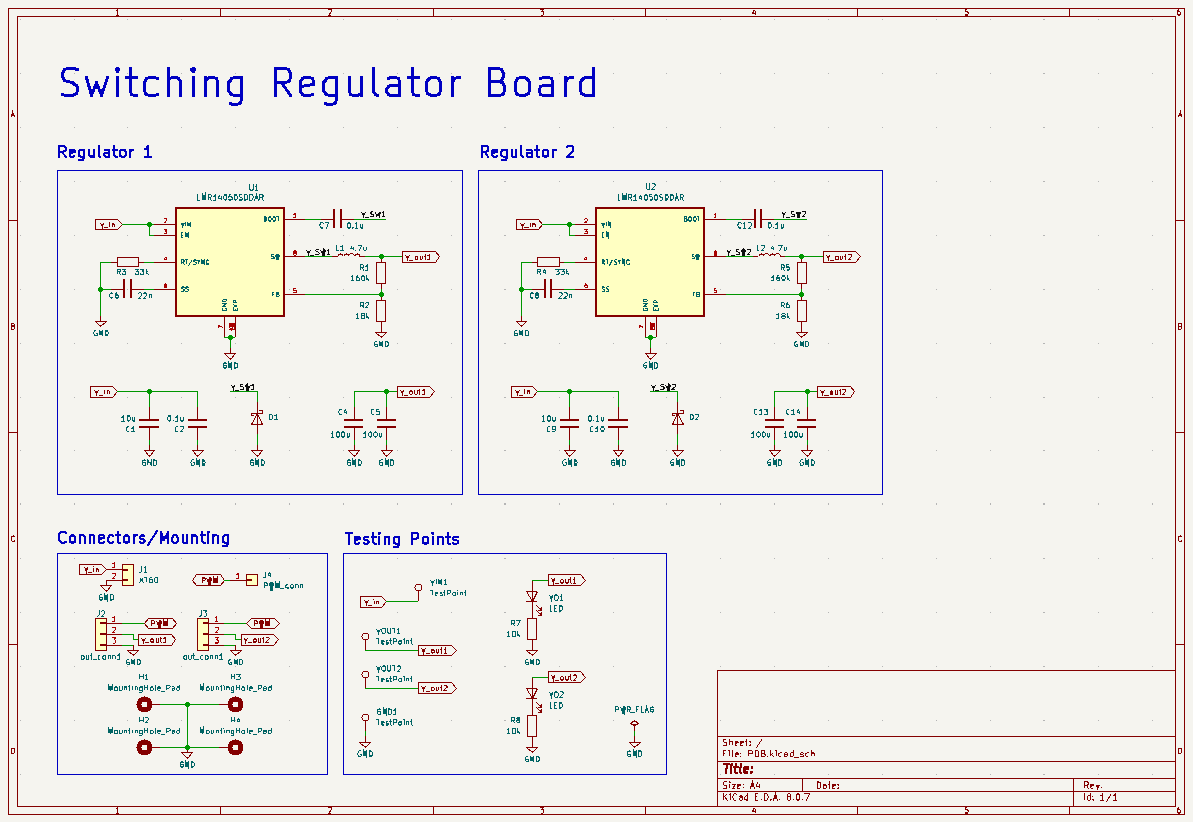
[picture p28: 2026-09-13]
pcb/PCB1/pictures/schematic.png

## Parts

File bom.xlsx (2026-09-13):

Project Title: Auto-tranforming Robot S.N.A.S.H.
Group ID: MON - 10
Name of the Group Member/s: Harshil Singla, Arin Weling, Sthiti Padhi, Saumya Shah, Neel Rambhia
Contact details of the Group Member responsible for BOM: Harshil Singla (+91 9817210635, 22b1260@iitb.ac.in)
BOM
Sr.No | Usage (Name of the "Circuit block/Functional block" in which components is used) | Part description (OpAMP,ADC,DAC etc) | Manufacturing Part Number | Package type/Footprint | Availiabile in WEL? | WEL Component stock Location-ID | Vendor | Stock Availiability (With Vendor) | Link (Vendor online website) | Required Qty + Spare | Cost per each item | Total Cost
1 | Flight Controller | Speedy Bee | F405 V4 55A | N.A. | No | N.A. | Robu | Out-of-Stock | https://robu.in/product/speedybee-f405-v4-bls-55a-30x30-fc-amp-esc-stack/ | 1+0 | 6399 | 6399
2 | RC Controller | RadioMaster Pocket Radio Controller | ELRS Version | N.A. | No | N.A. | Robu | In-Stock | https://robu.in/product/radiomaster-pocket-radio-controller-elrs-version-transparent/?gQT=2 | 1+0 | 6020 | 6020
3 | RC Receiver | Radiomaster RP3 Receiver | ESP8285 | N.A. | No | N.A. | Robu | In-Stock | https://robu.in/product/radiomaster-rp3-v2-expresslrs-2-4ghz-nano-receiver/?gad_source=1 | 1+0 | 2750 | 2750
4 | Battery | 14.8V 2200mAh 40C 4S LiPo Battery | ORANGE 2200/4S-40C | N.A. | No | N.A. | Robu | In-Stock | https://robu.in/product/orange-2200mah-4s-40c80c-lithium-polymer-battery-pack-lipo/ | 1+1 | 1869 | 3738
5 | Servo Motor | Metal Gear Digital Servo Motor | OT5330M | N.A. | No | N.A. | Robu | Out-of-Stock | https://robu.in/product/orange-ot5330m-7-4v-35-5kg-cm-180-metal-gear-digital-servo-motor/ | 4+0 | 1799 | 7196
6 | DC Motor | Micro Metal Gear-box DC Motor | N20-12V-60 RPM | N.A. | No | N.A. | Robu | In-Stock | https://robu.in/product/n20-12v-60-rpm-micro-metal-gear-box-dc-motor/ | 4+4 | 223 | 1784
7 | BLDC Motor | FPV Drone motor | FS 2207.5 2550KV-4S | N.A. | No | N.A. | Robu | In-Stock | https://robu.in/product/turbo-fpv-drone-motor-2/?gad_source=1 | 4+0 | 2694 | 10776
8 | Motor Driver | L298N | L298N | N.A. | No | N.A. | Robu | In-Stock | https://robu.in/product/l298n-2a-based-motor-driver-module-good-quality/?gad_source=1 | 1+0 | 92 | 184
11 | Voltage Regulator | 14.8V to 7.4V Step Down Switching Regulator | LMR14050SDDAR | 8-PowerSOIC | No | N.A. | Robu | In-Stock | https://robu.in/product/lmr14050sddar-texas-instruments-buck-switching-regulator-ic-positive-adjustable-0-8v-1-output-5a-8-powersoic-0-154-3-90mm-width/ | 4+2 | 104 | 624
12 | Voltage Regulator | Schottky Diode 5A | SS54 | SMA(DO-214AC) | No | N.A. | Robu | In-Stock | https://robu.in/product/ss54-slkor-40v-550mv5a-5a-smado-214ac-schottky-diodes-rohs/ | 4+4 | 5 | 40
13 | Voltage Regulator | 0.1uF 16V Capacitor | MC0603B104M160CT | 0603 Package | No | N.A. | Robu | In-Stock | Buy MC0603B104M160CT-MULTICOMP PRO-CERAMIC CAPACITOR, 0.1UF, 16V, X7R, 20%, 0603 Online (https://robu.in/product/mc0603b104m160ct-murata-ceramic-capacitor-0-1uf-16v-x7r-20-0603/) | 8+4 | 2 | 8
10 | Voltage Regulator | 4.7uH SMD Power Inductor | SRP3212A-4R7M | 1210 (3225 Package) | Yes | 2K.BOX-9.102 | N.A. | N.A. | https://www.digikey.com/en/products/detail/bourns-inc/SRP3212A-4R7M/16546463 | 4+1 | 22 | 22
10 | Voltage Regulator | 22uF Capacitor | - | 0603 Package | Yes | 2N | N.A. | N.A. | - (https://www.digikey.com/en/products/detail/bourns-inc/SRP3212A-4R7M/16546463) | 2+1 | - | -
10 | Voltage Regulator | 10k Resistor | - | 0603 Package | Yes | 2M | N.A. | N.A. | - (https://www.digikey.com/en/products/detail/bourns-inc/SRP3212A-4R7M/16546463) | 1+1 | - | -
10 | Voltage Regulator | 13k Resistor | - | 1206 Package | Yes | 2M | N.A. | N.A. | - (https://www.digikey.com/en/products/detail/bourns-inc/SRP3212A-4R7M/16546463) | 1+1 | - | -
10 | Voltage Regulator | 110k Resistor | - | 1206 Package | Yes | 2M | N.A. | N.A. | - (https://www.digikey.com/en/products/detail/bourns-inc/SRP3212A-4R7M/16546463) | 1+1 | - | -
14 | Voltage Regulator | 10uF 35V | - | N.A. | Yes | 2L.BOX-2.48 | N.A. | N.A. | - | 4+4 | - | -
15 | Voltage Regulator | 100uF 25V | - | N.A. | Yes | 2N | N.A. | N.A. | - | 12+4 | - | -
16 | Propeller | 6 inch propellers | - | N.A. | No | N.A. | Robu | In-Stock |  | 4+4 | 240 | 240
17 | Flange Bearing | Ball Bearing | - | N.A. | No | N.A. | Robu | In-Stock | https://robu.in/product/8mm-inner-diameter-zinc-alloy-pillow-block-flange-bearing-kfl08/ | 4+2 | 73 | 438
18 | Electrical Wiring | XT60 Connectors | - | N.A. | No | N.A. | Robu | In-Stock | https://robu.in/product/xt60h-connector-with-housing-male/ | 10+0 | 32 | 320
19 | Mechanical Assembly | Battery Box (3D Printed - PLA) |  |  |  |  |  |  |  | 1+0
20 | Mechanical Assembly | Side Plates + Servo Plates (Laser Cut - 5mm Acrylic Sheet) |  |  |  |  |  |  |  | 2+2
21 | Mechanical Assembly | Top Plate (Laser Cut - 5mm Acrylic Sheet) |  |  |  |  |  |  |  | 1+0
22 | Mechanical Assembly | Bottom Plate (Laser Cut - 5mm Acrylic Sheet) |  |  |  |  |  |  |  | 1+0
23 | Mechanical Assembly | Wheels (3D Printed - PLA) |  |  |  |  |  |  |  | 4+4
24 | Mechanical Assembly | Legs (3D Printed - PLA) |  |  |  |  |  |  |  | 4+4
25 | Mechanical Assembly | Screws and Nuts (M2, M3, M4) |  |  |  |  |  |  | Local Shop
26 | Mechanical Assembly | Zip Tie |  |  |  |  |  |  | Local Shop
28 | Mechanical Assembly | Outer Gear (Laser Cut - 3 mm Acrylic Sheet) |  |  |  |  |  |  |  | 4+4
29 | Mechanical Assembly | Inner Gear (Laser Cut - 5 mm Acrylic Sheet) |  |  |  |  |  |  |  | 4+4
30 | Electrical Wiring | AWG Wires
 |  |  |  |  |  |  |  |  |  |  | Total | 40539

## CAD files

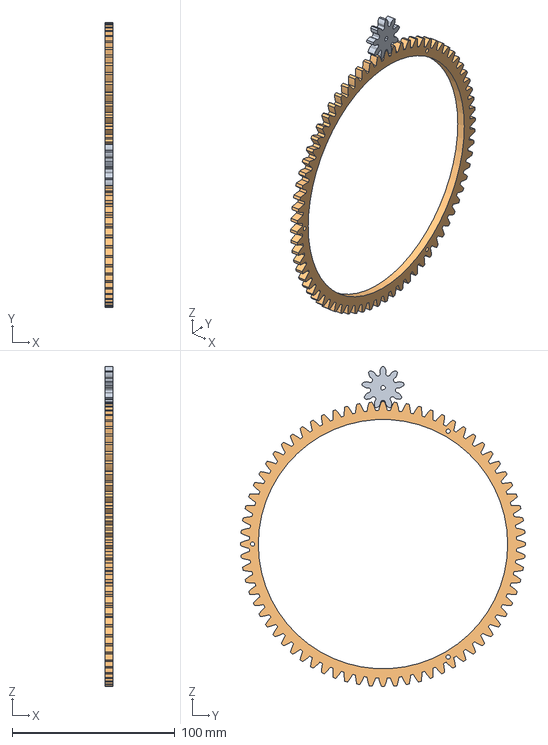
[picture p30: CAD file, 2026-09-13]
3d_models/Wheel_assembly/Gears/Gear_Assembly_v4.step
5.00 x 174.7 x 196.3 mm

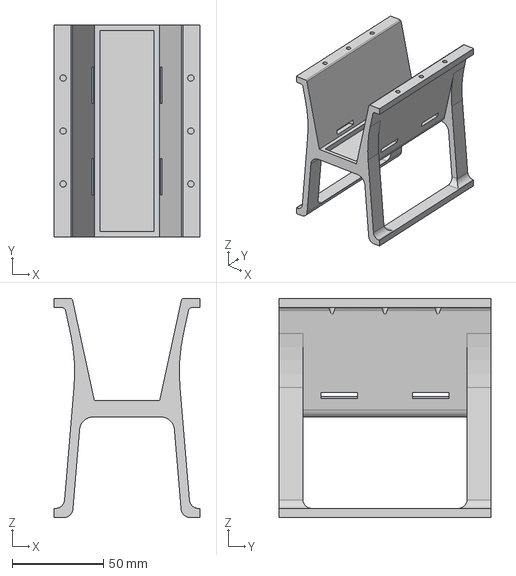
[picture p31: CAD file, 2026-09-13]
3d_models/Chassis/Battery_Box/Battery_Box_v9.step
80.0 x 116.0 x 120.0 mm

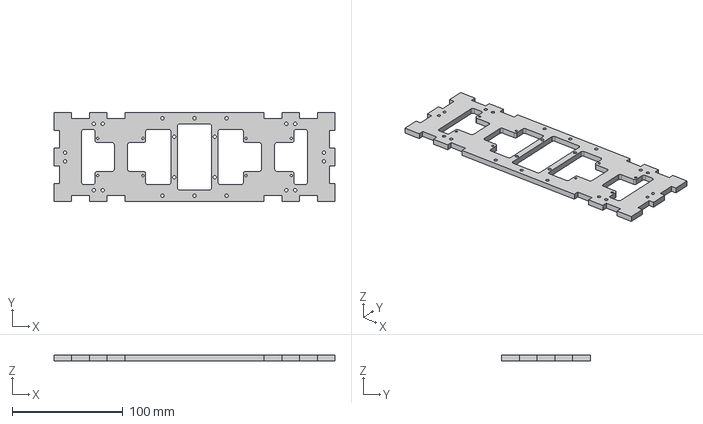
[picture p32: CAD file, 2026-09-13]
3d_models/Chassis/Bottom_Plate/Bottom_Plate_v17.step
254.0 x 80.0 x 5.00 mm

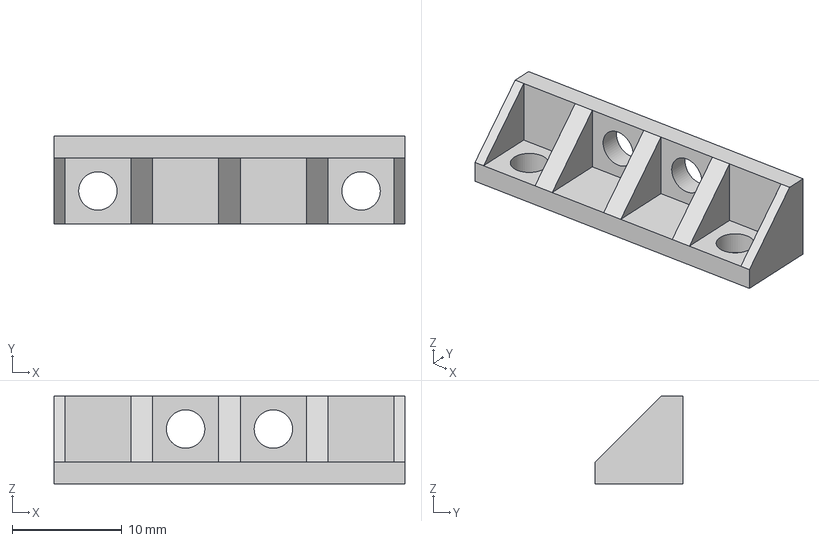
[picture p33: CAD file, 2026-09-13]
3d_models/Chassis/L_Joint/LJoint_v4.step
32.0 x 8.00 x 8.00 mm

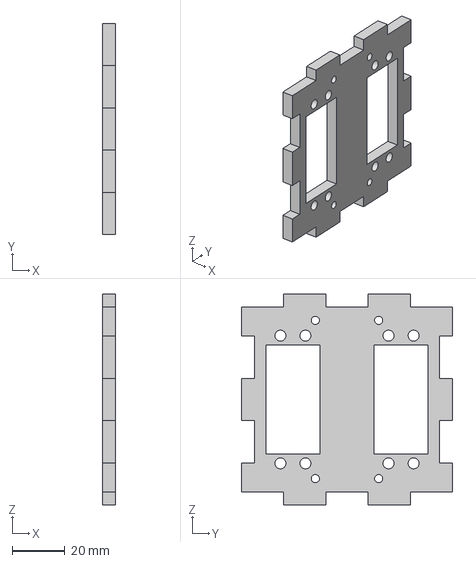
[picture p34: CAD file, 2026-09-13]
3d_models/Chassis/Servo_Plate/Servo_Plate_v17.step
5.00 x 80.0 x 80.0 mm

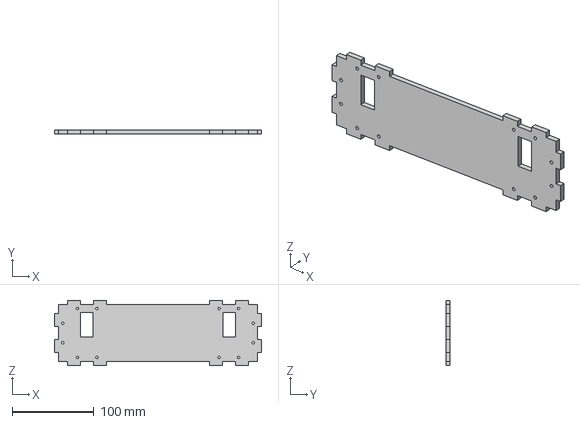
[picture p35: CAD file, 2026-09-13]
3d_models/Chassis/Side_Plate/Side_Plate_v1.step
254.0 x 5.00 x 80.0 mm

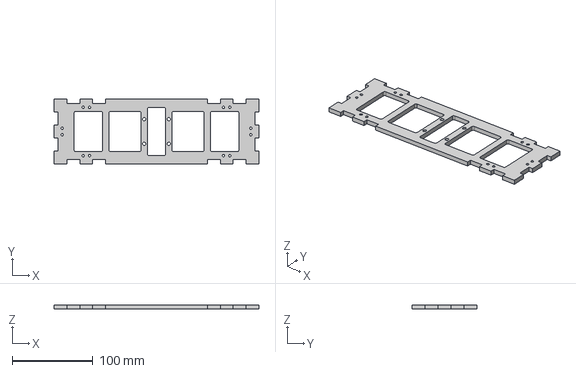
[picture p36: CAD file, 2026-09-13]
3d_models/Chassis/Top_Plate/Top_Plate_v14.step
254.0 x 80.0 x 5.00 mm

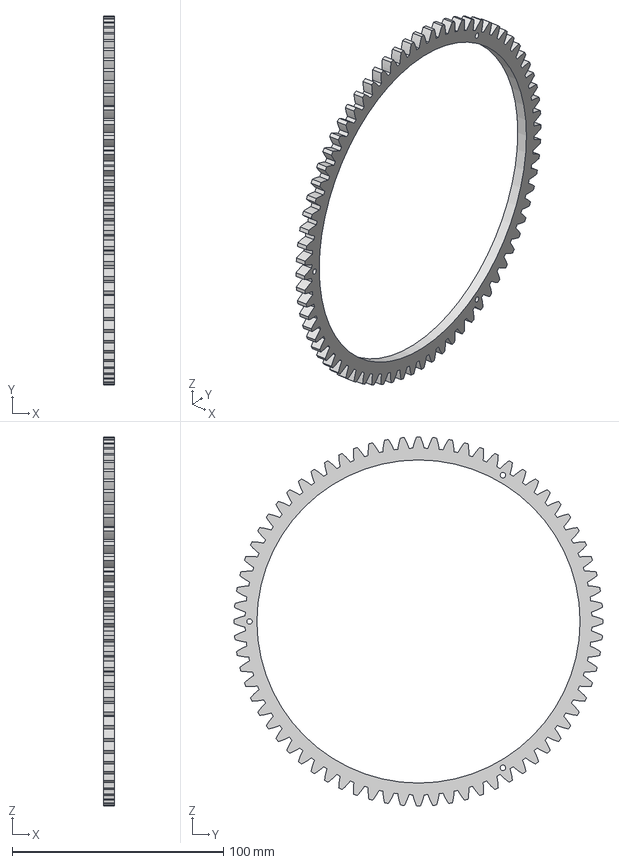
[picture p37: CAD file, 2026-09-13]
3d_models/Wheel_assembly/Gears/Gear_big_v3.step
5.00 x 174.7 x 174.7 mm

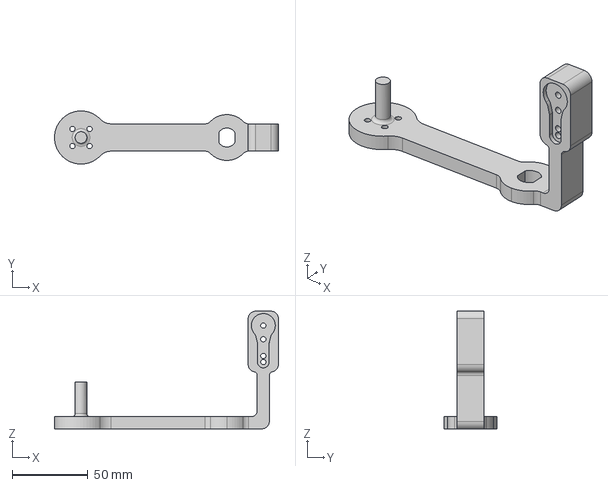
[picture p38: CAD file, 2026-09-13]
3d_models/Wheel_assembly/Leg/Leg_OnePiece_v16.step
147.5 x 35.0 x 77.5 mm

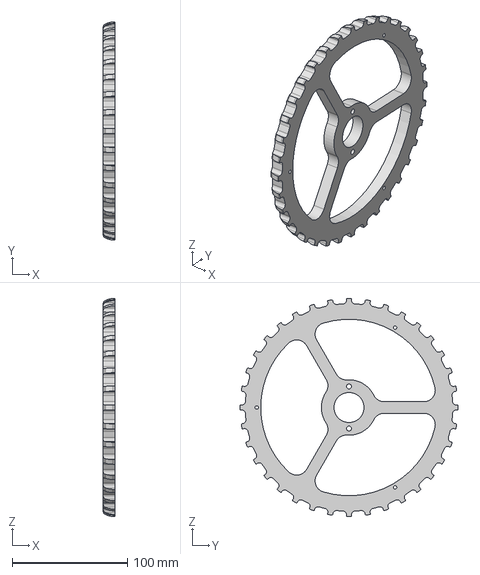
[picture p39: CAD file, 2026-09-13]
3d_models/Wheel_assembly/Wheel/wheel_v3.step
10.0 x 189.0 x 189.0 mm

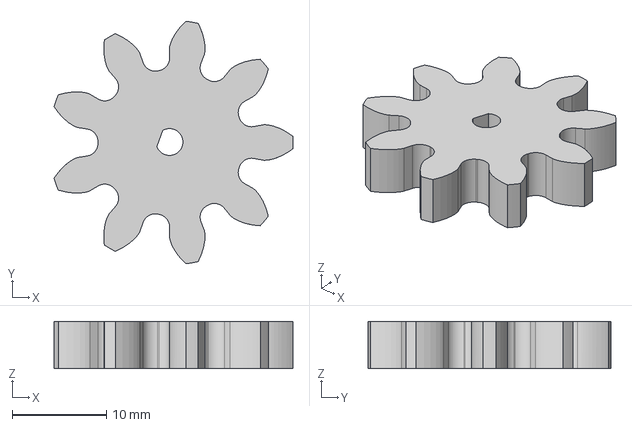
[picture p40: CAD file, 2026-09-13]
3d_models/Wheel_assembly/Gears/Gear_small_v7.step
25.4 x 25.8 x 5.00 mm

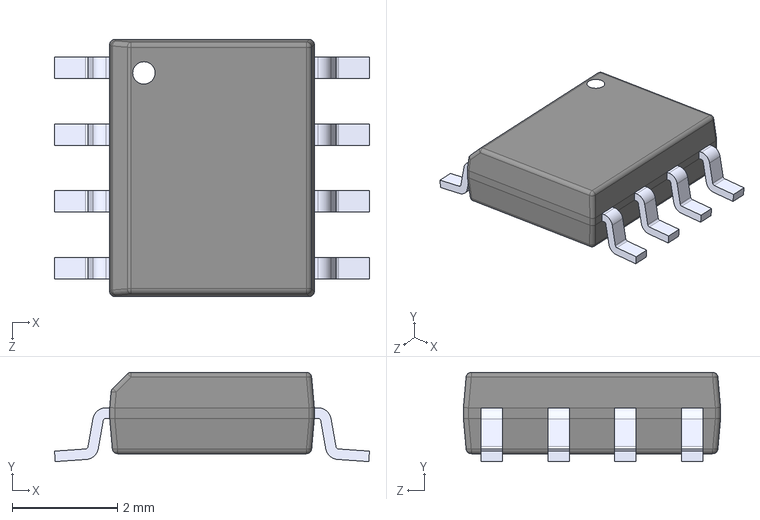
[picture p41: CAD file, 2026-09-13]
pcb/Resources/LMR14050SDDAR/LMR14050SDDAR.step
6.00 x 1.70 x 4.90 mm

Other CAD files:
Ardupilot/Tools/autotest/aircraft/arducopter/Models/Untitled.skp
Ardupilot/Tools/autotest/aircraft/arducopter/Models/Y6_test.skp
Ardupilot/Tools/autotest/aircraft/arducopter/Models/Y6_test2.skp
Ardupilot/Tools/autotest/aircraft/arducopter/Models/_propeller0_.skp
Ardupilot/Tools/autotest/aircraft/arducopter/Models/plus_quad.skp
Ardupilot/Tools/autotest/aircraft/arducopter/Models/plus_quad2.skp
Ardupilot/Tools/autotest/aircraft/arducopter/Models/quad.skp

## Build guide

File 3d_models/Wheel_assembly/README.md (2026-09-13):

Wheel Assembly Components:
- [Leg](./Leg)
- [Wheel](./Wheel)
- [Gears](./Gears)
  
Wheels and legs were 3D printed while the gears were laser cut.<br>
The wheel was fastened to the gear using M2 screws.<br>
The wheel was fastened to the leg through a flange bearing (KFL08) to decouple it from the rest of the leg.<br>
The wheel was fastened to the bearing using M4 screws while the leg was fastened through the in-built grubs.

The leg was 3D printed at max infill (90%) to ensure structural integrity of the shaft. The wheel was printed at 30% infill. Both of the big gears were laser cut using 3mm acrylic sheet to make a total 6mm thickness. The small gear attached to DC motor was laser cut using 5mm acrylic sheet.

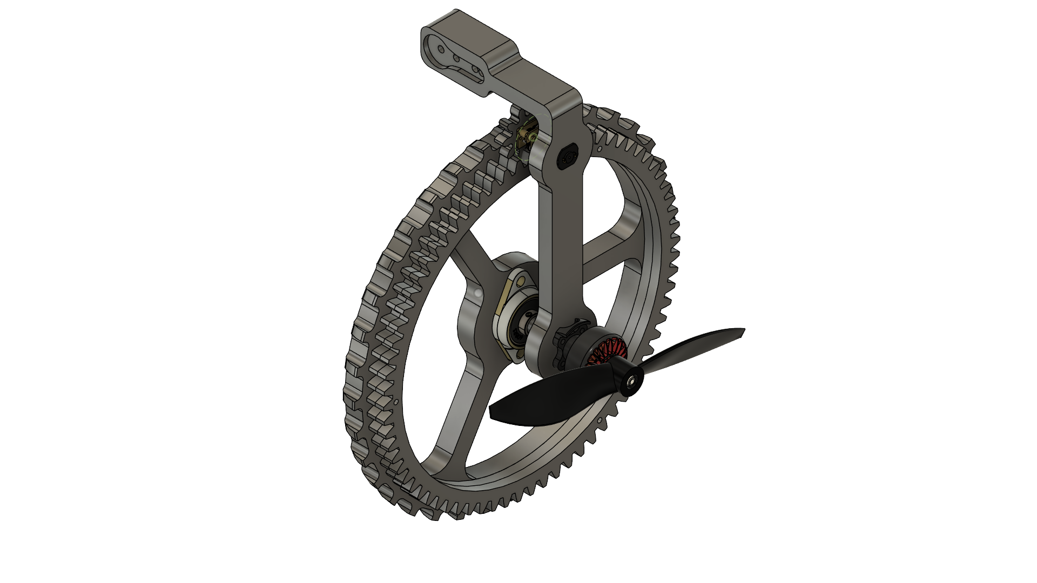
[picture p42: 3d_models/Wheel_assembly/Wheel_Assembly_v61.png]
Wheel Assembly


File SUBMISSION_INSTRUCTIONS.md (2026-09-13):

# Project Documentation and Submission Guide

This document serves as a comprehensive guide for your project submission. By following the instructions below, you will ensure that the project is properly organized, documented, and easy for others (such as professors or staff members) to understand and replicate.

Your entire project is graded based on this submission and so please adhere to this properly. Stick to the hard deadline given and NO EXTENSIONS WILL BE GRANTED AT ANY POINT IF IT IS NOT COMPLETED.

## Project Overview

### Project Name: [Insert Project Name Here]
### Team Number: [MON/TUE-xx]
### Team Members:
- [Name 1]
- [Name 2]
- [Name 3]
- [Name 4]
- [Name 5] (if applicable)

### Problem Statement and Solution:

Provide a description about the project and what you've learnt and achieved in this.

Make sure to add all the below properly as given and if it's applicable.

## 1. Source Code

All source code files should be organized under the `/src` directory. If your project involves multiple microcontrollers or processors, create respective subfolders for each and provide clear descriptions about their purpose and functionality. Every subfolder should have a README.MD file which should explain the purpose of the code and all the commands used.

### Folder Structure:
```plaintext
/Project-Root 
├── /src # Source code folder (Add your source files here) 
  ├── /microcontroller1 # Code for Microcontroller 1 
    ├── file1.c # General source file 
    ├── file2.c
  ├── /microcontroller2 # Code for Microcontroller 2 (if applicable) 
    ├── file1.c # General source file 
    ├── file2.c
```

### Guidelines for Organizing Code:
1. **Microcontroller-specific code**:  
   If your project involves multiple microcontrollers, create a folder for each one under `/src`. Provide the following details:
   
   - **Folder Name**: Name it according to the microcontroller, e.g., `Microcontroller1`, `Microcontroller2`.
   - **Description**: A brief description of what each microcontroller’s source code does and its role in the project in a README.md file.

Example:
```plaintext
/src 
  ├── /<microcontroller_name1> 
    ├── <relevant_sources.c>  # All source codes
    ├── README.md  # Clear Documentation on the usage of board along with the commands and steps performed
  ├── /<microcontroller_name2> 
    ├── <relevant_sources.c>  # All source codes
    ├── README.md  # Clear Documentation on the usage of board along with the commands and steps performed
......
......
```

2. **Running the Application**:
- If your project is based on microcontroller code, provide detailed instructions on how to upload and run the code on the microcontroller. This should include:
  - The microcontroller model (e.g. STM32, RPi Pico).
  - The Integrated Development Environment (IDE) used for programming (e.g., STM32CubeIDE, VSCode, Thonny IDE).
  - Steps for compiling and uploading the code to the device.
  - Example command to upload (if applicable).

3. **Code Comments**:
- Every source file should be properly commented to describe the purpose and function of each section of code.
- If you have made modifications to an existing code template or framework, comment clearly with your team name and indicate what changes were made.

---

## 2. PCB Design (If Applicable)

If your project involves designing a printed circuit board (PCB), provide the design files in the `/pcb` folder. If you have multiple PCBs, create separate subfolders for each design. Mention the tool used to design the PCB. (KiCAD, Altium, EAGLE). Include the picture of your final PCB Layout (With visibility of all the layers) under the `/pcb/<PCB_X>/pictures` folder with the layer names along with the picture of the Printed PCB which you've obtained.

### Folder Structure:
```plaintext
/Project-Root 
├── /pcb 
  ├── /PCB1 # First PCB Design 
    ├── design.kicad_pcb # PCB Design in KiCAD format 
    ├── schematic.sch # KiCAD Schematic 
  ├── /PCB2 # Second PCB Design (if applicable) 
    ├── design.sch # PCB Schematic
    ├── design.kicad_pcb # PCB Design in KiCAD format 
```
Include all relevant design files such as schematics, board layouts, custom schematic and footprints used and imported if applicable.

---

## 3. 3D Models / Laser Cuts

If your project includes 3D models or components that require laser cutting, place these files in the `/3d_models` directory. Create separate subfolders for different models and provide a description of the design process and tools used.

### Folder Structure:
```plaintext
/Project-Root 
├── /3d_models 
  ├── /component1 # 3D Model for Component 1 
    ├── model.stl # 3D model file 
    ├── picture.png # Rendered image of the 3D model 
  ├── /component2 
    ├── model.obj 
    ├── picture.jpg
```
Make sure to also include images (e.g., PNG, JPG) of the components that were laser cut or 3D printed.

---

## 4. Bill of Materials (BOM)

Provide a complete Bill of Materials (BOM) listing all the hardware components used in your project. This should include both parts obtained from the lab and parts ordered from external vendors or purchased locally.

### Folder Structure:
```plaintext
/Project-Root 
├── bom.xls # Excel sheet listing components
```

### BOM Details:
The `bom.xls` file should include the following columns:
- **Component Name**
- **Type** (3D Model / Modules / IC / Consumables / Sensors & Actuators)
- **Quantity**
- **Part Number** (if applicable)
- **Supplier/Manufacturer/Vendor/Purchased Place**
- **Cost**
- **Description**

---

## 5. Reports and Presentations

Provide your project presentation and reports in either `.pptx`, `.ppt`, or `.pdf` format. This should include a brief overview of your project, objectives, design process, results, and conclusions. This should include all the milestone submission presentations.

### Folder Structure:
```plaintext
/Project-Root
  ├── /reports 
    ├── presentation.pptx # PowerPoint presentation file
    ├── milestone_reports.pdf # Milestone Reports in PDF file
```

## 6. Other Documents

Provide the wiring diagram of your components, attach pictures of your final project on how did you assemble the design. Place these files in the `/others` directory.
Any other important information regarding your project if it doesn't fit into any of the above categories, add it into this subfolder along with a proper README.md file to explain the same.

## Final Notes:
- **Documentation**: Ensure that all your files are well-documented. This includes commenting your code, describing your designs, and providing detailed instructions in your README file.

By following these instructions, your project will be well-organized, easy to understand, and reproducible by others, including professors or staff members who might need to verify or recreate your project in the future.

Thank you, and best of luck with your project!

---

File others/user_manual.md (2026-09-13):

# 🤖 MorphoBot User Manual

---

## ⚠️ Precautions

1. **Place the bot on level ground** with the wheels in the drive position to avoid jerks during power-up.
2. **Turn on the RC transmitter first**, ensuring all buttons and analog sticks are at their **zero positions**, for faster binding.
3. **Tighten all screws on the main chassis** after each flight to prevent mishaps.
4. **Ensure propellers are securely fastened** before powering on.
5. **Check battery voltage** — it should be between **14.8 V and 16.8 V**. If not, charge the battery using a standard LiPo charger by using the 4S settings to fuly charge the battery upto 16.8 V.
6. **Inspect parts for cracks** and replace any damaged components immediately.
7. **Ensure all wires are intact and untangled**, especially near the wheel assembly and propellers in drive and drone modes.

---

## 🚀 Getting Started

### Step 1: Power On the Transmitter
- Switch on the **RC transmitter**.
- Ensure all buttons and analog sticks are in the **zero position**.

### Step 2: Position the Bot
- Place the bot on a **flat surface**.
- Ensure the **wheels are in the drive position**, then power it on.

### Step 3: Initialization
- Do **not move the bot** while it initializes to allow proper **gyroscope calibration**.

### Step 4: Ready to Go!
- The bot is now ready to use in **Drive Mode**.

---

## 🛞 Drive Mode

- **Activated when:** `SB` and `SC` switches are in the **low** position.
- **Control Stick:** Use the **right analog stick**.

### Controls:
- **Forward/Backward:** Move the right stick **vertically**.
- **Turning:**
  1. Move the right stick **left/right** to choose turn direction.
  2. While holding the horizontal direction, adjust the **vertical** position to control turning **speed**.

---

## 🛸 Drone Mode

1. **Arm the drone** by pressing the `SA` button — the BLDC motors will begin spinning at low RPM.
2. **Throttle & Yaw:** Controlled using the **left analog stick**.
3. **Pitch & Roll:** Controlled using the **right analog stick**.

Basic Drone Controls

---

## 🔄 Switching Between Modes

### 🚗 Drive Mode → 🛸 Drone Mode

1. Press the `SD` button to enter **Gear Up Mode**.
2. Move the `SC` switch to the **middle** position. Wait for the bot to **morph** into drone mode.
3. Once fully morphed, set `SC` to the **highest** position to enter **Stabilized Flight Mode**.
4. With `SC` in the **highest** position, set `SB` to the **middle** and **highest** positions to enter the **Acro** and **Pos hold**  modes respectively. 

### 🛸 Drone Mode → 🚗 Drive Mode

1. Unpress the `SA` button to **disarm** the BLDC motors.
2. Unpress the `SD` button to enter **Gear Down Mode**.
3. Move the `SC` switch to the **middle** position. Wait for the bot to **morph** into drive mode.
4. Once in drive position, move `SC` to the **lowest** position to return to **Drive Mode**.

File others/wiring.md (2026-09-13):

1. As seen in the image, the SpeedyBee is kept on the top plate so that all connections from it can be simply made to other components. The motor driver (L298N) and both PCB's are kept on the bottom plate and all PWM connections are made to the SpeedyBee.
2. The ELRS receiver is soldered directly to the SpeedyBee and kept on top. 
3. Further connections between the SpeedyBee ESC and the BLDC motors are made directly.
4. The DC motors are connected to the output of the L298N and the two motors on each side are connected to the same output (since they will always rotate in the same direction and speed).
5. Power is given by the battery using an XT60 connector to the SpeedyBee and 1 PCB. Wires are soldered from this PCB's power terminals to the other PCB and L298N.
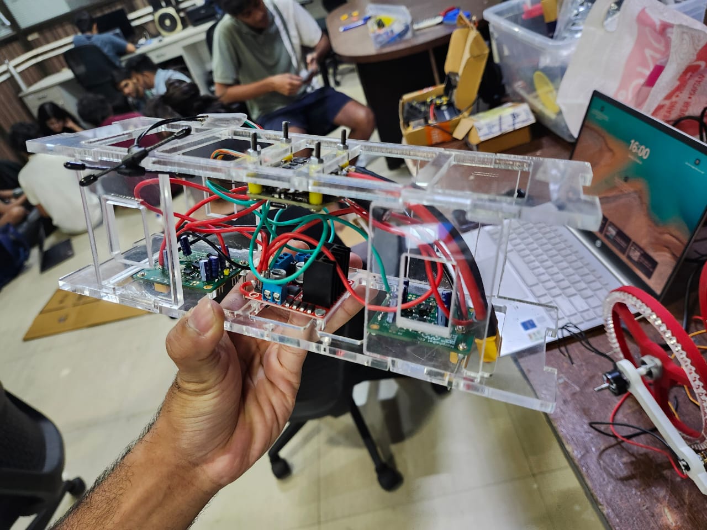
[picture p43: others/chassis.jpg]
Chassis Assembled Image


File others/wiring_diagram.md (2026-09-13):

wiring_diagram drawio

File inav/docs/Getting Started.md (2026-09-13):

# Getting Started

This is a step-by-step guide that can help a person that has never used INAV before set up a flight controller and the aircraft around it for flight. Basic RC knowledge is required, though. A total beginner should first familiarize themselves with concepts and techniques of RC before using this (e.g. basic controls, soldering, transmitter operation etc). One could use [RCGroups](http://www.rcgroups.com/forums/index.php) and/or [the Youtube show FliteTest](https://www.youtube.com/user/flitetest) for this.

DISCLAIMER: This documents is a work in progress. We cannot guarantee the safety or success of your project. At this point the document is only meant to be a helping guide, not an authoritative checklist of everything you should do to be safe and successful. Always exercise common sense, critical thinking and caution.

Read the [Introduction](Introduction.md) chapter for an overview of INAV and how the community works.

## Hardware

NOTE: Flight Controllers are typically equipped with accelerometers. These devices are sensitive to shocks. When the device is not yet installed  to an aircraft, it has very little mass by itself. If you drop or bump the controller, a big force will be applied on its accelerometers, which could potentially damage them. Bottom line: Handle the board very carefully until it's installed on an aircraft!

For an overview of the hardware INAV (hereby CF) can run on, see [Boards.md](Boards.md). For information about specific boards, see the board specific documentation.

* Assuming that you have a flight controller board (hereby FC) in hand, you should first read through the manual that it came with. You can skip the details about software setup, as we'll cover that here.

* Decide how you'll connect your receiver by reading the [receiver](Rx.md) chapter, and how many pins you need on the outputs (to connect ESCs and servos) by reading about [Mixers](Mixer.md).

* If you're interested in monitoring your flight battery with CF, see [Battery Monitoring](Battery.md).

* You may want audible feedback from your copter so skim through [Buzzer](Buzzer.md) and mark the pins that will be used.

* Do you want your RC Receiver's RSSI to be sent to the board? [The RSSI chapter](Rssi.md) explains how. You may or may not need to make an additional connection from your Receiver to the FC.

* Would you like to try using a GPS unit to get your aircraft to Loiter or Return-To-Launch? Take a look at the [GPS](Gps.md) and [GPS Tested Hardware](Gps.md#hardware) chapters.

* You may also want to read the [Serial](Serial.md) chapter to determine what extra devices (such as Blackbox, OSD, Telemetry) you may want to use, and how they should be connected.

* Now that you know what features you are going to use, and which pins you need, you can go ahead and solder them to your board, if they are not soldered already. Soldering only the pins required for the application may save weight and contribute to a neater looking setup, but if you need to use a new feature later you may have to unmount the board from the craft and solder missing pins, so plan accordingly.  Before soldering your FC please review a how-to-solder tutorial to avoid expensive mistakes, practice soldering on some scrap before soldering your FC.

* If you are going to use [Oneshot125](Oneshot.md), you may need to enable that on your ESCs using a jumper or flashing them with the latest stable firmware and enable Damped Light in their settings, if it's supported. Refer to the ESCs' documentation or online discussions to determine this.

## Software setup

Now that your board has pins on it, you are ready to connect it to your PC and flash it with CF. Install the Chromium browser or Google Chrome to your PC, if you don't have it already, add the [INAV Configurator](https://chrome.google.com/webstore/detail/inav-configurator/fmaidjmgkdkpafmbnmigkpdnpdhopgel) to it, and start it.

Then follow these instructions for [Installation](Installation.md) of the firmware to the FC.

## INAV Configuration

Your FC should now be running CF, and you should be able to connect to it using the Configurator. If that is not the case, please go back to the previous sections and follow the steps carefully.

<!--- This next paragraph should probably contain less info, as this info already exists in Configuration.md -->
Now, there are two ways to [configure CF](Configuration.md); via  the Configurator's tabs (in a "graphical" way, clicking through and selecting/changing values and tickboxes) and using the [Command Line Interface (CLI)](Cli.md). Some settings may only be configurable using the CLI and some settings are best configured using the GUI (particularly the ports settings, which aren't documented for the CLI as they're not human friendly).

* It is now a good time to setup your RC Receiver and Transmitter. Set the Tx so that it outputs at least 4 channels (Aileron, Elevator, Throttle, Rudder) but preferably more. E.g. you can set channels 5 and 6 to be controlled by 3-position switches, to be used later. Maybe set up EXPO on AIL/ELE/RUD, but you should know that it can also be done in CF's software later. If using RSSI over PPM or PWM, it's now time to configure your Rx to output it on a spare channel.

* Connect the Rx to the FC, and the FC to the PC. You may need to power the Rx through a BEC (its 5V rail - observe polarity!).

* On your PC, connect to the Configurator, and go to the first tab. Check that the board animation is moving properly when you move the actual board. Do an accelerometer calibration.

* Configuration tab: Select your aircraft configuration (e.g. Quad X), and go through each option in the tab to check if relevant for you.

  * E.g. you may want to enable ONESHOT125 for Oneshot-capable ESCs.
  * You may need RX_PPM if you're using an RC Receiver with PPM output etc.
  * If planning to use the battery measurement feature of the FC, check VBAT under Battery Voltage.
  * If using analog RSSI, enable that under RSSI. Do not enable this setting if using RSSI injected into the PPM stream.
  * Motors will spin by default when the FC is armed. If you don't like this, enable MOTOR_STOP.
  * Also, adjust the minimum, middle and maximum throttle according to these guidelines:

    * Minimum Throttle - Set this to the minimum throttle level that enables all motors to start reliably. If this is too low, some motors may not start properly after spindowns, which can cause loss of stability and control. A typical value would be 1100.
    * Middle Throttle - The throttle level for middle stick position. Many radios use 1500, but some (e.g. Futaba) may use 1520 or other values.
    * Maximum Throttle - The maximum throttle level that the ESCs should receive. A typical value would be 2000.
    * Minimum Command - This is the "idle" signal level that will be sent to the ESCs when the craft is disarmed, which should not cause the motors to spin. A typical value would be 1000.
  * Finally, click Save and Reboot.

* Receiver tab:
    * Check that the channel inputs move according to your Tx inputs.
    * Check that the Channel map is correct along with the RSSI Channel, if you use that.
    * Verify the range of each channel goes from ~1000 to ~2000.  See also [controls](Controls.md). and `rx_min_usec` and `rx_max_usec`.
    * You can also set EXPO here instead of your Tx.
    * Click Save!
* Modes tab: Setup the desired modes. See the [Modes in the wiki](https://github.com/iNavFlight/inav/wiki/Modes) for what each mode does.

* Before finishing this section, you should calibrate the ESCs, install the FC to the frame, and connect the RSSI cable, buzzer and battery if you have chosen to use those.

## Final testing and safety

It's important that you have configured CF properly, so that your aircraft does not fly away, or even worse fly into property and people! This is an important step that you should NOT postpone until after your maiden flight. Please do this now, before you head off to the flying field.

* First, learn how to arm your FC, and about other [controls](Controls.md).
* Next up, setup [Failsafe](Failsafe.md). Take your time, do it properly.
* Now, on the bench, without props, test that failsafe works properly, according to the above doc.
* Additionally, test the effect of AIL/ELE input of your Tx. Is the aircraft responding properly? Do the same for RUD input.
* Test the direction of AIL/ELE auto correction. Raise throttle at 30% (no blades!); when you tilt the aircraft, do the motors try to compensate momentarily? This should simulate random wind forces that the FC should counteract
* Test the direction of AIL/ELE auto correction in HORIZON mode. With throttle at 30%, if you tilt the aircraft so that one motor is lowered towards the ground, does it spin up and stay at high RPM until you level it off again? This tests the auto-leveling direction.

If one of these tests fail, do not attempt to fly, but go back to the configuration phase instead. Some channel may need reversing, or the direction of the board is wrong.

## Using it (AKA: Flying)

Go to the field, turn Tx on, place aircraft on the ground, connect flight battery and wait. Arm and fly. Good luck!

## Advanced Matters

Some advanced configurations and features are documented in the following pages, but have not been touched-upon earlier:

* [Profiles](Profiles.md)
* [PID tuning](PID%20tuning.md)
* [In-flight Adjustments](Inflight%20Adjustments.md)
* [Blackbox logging](Blackbox.md)
* [Using a Sonar](Sonar.md)
* [Spektrum Bind](Spektrum%20bind.md)
* [Telemetry](Telemetry.md)
* [Using a Display](Display.md)
* [Using a LED strip](LedStrip.md)

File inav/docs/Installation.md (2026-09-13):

# Installation

## Using the configurator
This is a generic procedure to flash a board using the configurator. The configurator does not yet support all boards, so please check the documentation corresponding to your board before proceeding.

Make sure you have the [INAV Configurator](https://github.com/iNavFlight/inav-configurator) installed, then:

* Connect the flight controller to the PC.
* Start the INAV Configurator.
* Click on "Disconnect" if the configurator connected to the board automatically.
* Click on the "Firmware Flasher" tab.
* Make sure you have internet connectivity and click on the "Load Firmware [Online]" button.
* Click on the "Choose a Firmware / Board" dropdown menu, and select the latest stable version for your flight controller.
* IMPORTANT: Read and understand the release notes that are displayed.  When upgrading review all release notes since your current firmware.
* If this is the first time INAV is flashed to the board, tick the "Full Chip Erase" checkbox.
* Connect the flight controller board to the PC.  Ensure the correct serial port is selected.
* Click on the "Flash Firmware" button and hold still (do not breathe, too).
* When the progress bar becomes green and reads "Programming: SUCCESSFUL" you are done!

## Manually

See the board specific flashing instructions.

# Upgrading

When upgrading be sure to backup / dump your existing settings.  Some firmware releases are not backwards compatible and default settings are restored when the FC detects an out of date configuration.

## Backup/Restore process

See the CLI section of the docs for details on how to backup and restore your configuration via the CLI.

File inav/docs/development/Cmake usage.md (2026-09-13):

# Cmake Usage

## Introduction

This guide documents INAV usage of the `cmake` build tool.

## Target Defintion

A target requires `CMakeLists.txt` file. This file contains one of more lines of the form:

```
target_hardware_definition(name optional_parameters)
```

For example:

```
target_stm32f405xg(QUARKVISION HSE_MHZ 16)
```

* The hardware is `stm32f405xg`, a F405 with a 1MiB flash
* The name is `QUARKVISION` (a board that never reached production)
* The optional parameter is `HSE_MHZ 16` defining the non-default high-speed external (HSE) oscillator clock.

## Hardware names

As of INAV 4.1, the following target hardware platforms are recognised:

* stm32f405xg
* stm32f411xe
* stm32f427xg
* stm32f722xe
* stm32f745xg
* stm32f765xg
* stm32f765xi
* stm32h743xi

The device characteristics for these names may be found at [stm32-base.org](https://stm32-base.org/cheatsheets/linker-memory-regions/).

## Optional Parameters

The following optional parameters are recognised:

| Paramater | Usage |
| --- | ----- |
| `SKIP_RELEASES` | The target is disabled for releases and CI. It still may be possible to build the target directly. |
| `COMPILE_DEFINITIONS "VAR[=value]"` | Sets a preprocessor define. |
| `HSE_MZ value` | The target uses a high-speed external crystal (HSE) oscillator clock with a frequency different from the 8MHz default. The `value` is the desired clock, for example `HSE_MHZ 24` |

Multiple optional parameters may be specified, for example `HSE_MHZ 16 SKIP_RELEASES`.

## Target variations

A number of targets support multiple variants, either successive versions of the same hardware, or varations that enable different resources (soft serial, leds etc.) This is defined by adding additional `target_` lines to `CMakeLists.txt`. For example, the OMNIBUSF4 and its multiple clones / variations, `src/main/target/OMNIBUSF4/CMakeLists.txt`:

```
target_stm32f405xg(DYSF4PRO)
target_stm32f405xg(DYSF4PROV2)
target_stm32f405xg(OMNIBUSF4)
# the OMNIBUSF4SD has an SDCARD instead of flash, a BMP280 baro and therefore a slightly different ppm/pwm and SPI mapping
target_stm32f405xg(OMNIBUSF4PRO)
target_stm32f405xg(OMNIBUSF4PRO_LEDSTRIPM5)
target_stm32f405xg(OMNIBUSF4V3_S5_S6_2SS)
target_stm32f405xg(OMNIBUSF4V3_S5S6_SS)
target_stm32f405xg(OMNIBUSF4V3_S6_SS)
# OMNIBUSF4V3 is a (almost identical) variant of OMNIBUSF4PRO target,
# except for an inverter on UART6.
target_stm32f405xg(OMNIBUSF4V3)
```

## Adding (or removing) a source file

In the cmake system, project source files are listed in `src/main/CMakeLists.txt`. New source files must be added to this list to be considered by the build system.

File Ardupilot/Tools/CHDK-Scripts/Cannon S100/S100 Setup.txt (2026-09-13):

Canon Settings

-On first power you will be asked to set the date and time.  Do this accurately (down to the minute).
-There are two menus, the system settings you get by pressing [MENU], and the photo settings you get by pressing [FUNC]
-Do the [MENU] settings first
-Place camera in "Program Auto" by setting the dial to [P]

[MENU]
[SHOOT SETTINGS] - first tab with the camera icon
Digital zoom 		>> 	Off
Continuous AF 		>> 	Off
AF-assist Beam 		>> 	Off
MF-Point zoom 		>> 	Off
Safety MF		>>	Off
Flash Settings 		...	
	Red-Eye Lamp	>> 	Off
	Safety FE	>> 	Off
Review			>> 	Off
IS Settings 		...
	IS Mode		>> 	Off
Face ID Settings	...	
	Face ID		>>	Off

[Camera Settings] - Second tab with tools icon
Lens Retract		>> 	0 sec.
Power Saving
	Auto Power Down	>>	Off
Time Zone		>>	Confirm set correctly
Date Time		>>	Confirm set correctly
GPS Auto Time		>>	On
GPS Settings		...
	GPS		>>	On (Confirm OK when prompted)

[FUNC]
Compression		>> 	Super Fine
White Balance		>> 	Daylight

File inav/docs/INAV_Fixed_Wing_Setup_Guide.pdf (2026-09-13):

# INAV FIXED WING SETUP GUIDE

By
Georgios Ntanas, Steve Schlesinger

Version 1.11 03/11/2019
New: If you’re experiencing technical problems please refer to the ‘INAV Trouble-Shooting Guide.’ (https://docs.google.com/document/d/1ljAr61u-4stSxGDyS6gu5KpiIpQUmmZL_gryUYHpyOc/edit?usp=sharing)

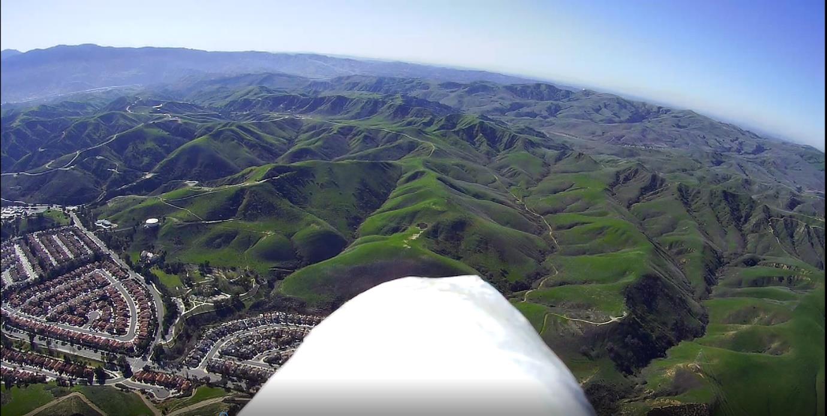
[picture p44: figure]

TABLE OF CONTENT

INTRODUCTION

This is a setup guide for the firmware on your INAV Flight Controller (FC). It is meant to be used after your aircraft is built and mechanically set up. If you are not there yet, don’t worry! There is a “Getting Started with INAV” document that covers things you need to know about getting your aircraft ready for INAV, before you dive in to setting up the firmware. This is near the bottom of this document in Appendix C. There are things you should know before working with your flight controller.

This setup guide started from notes that Georgios Ntanas (a group member) made from watching Pawel Spychalski’s YouTube videos on INAV. Pawel is an INAV developer and a group member. Thank you also to Leslie Wr (another group member) for bringing this document to our attention. Steve Schlesinger also modified the guide a bit, to highlight the sections people seem to struggle with the most.

This guide will take you through each menu item found on the left side of the INAV Configurator in the order they appear - top to bottom. This is the best way to approach setting up INAV. Since this guide is based on Pawel’s video, in each section we have put a link to the exact moment in the video where he discussed the specific tab. This will save you time searching for the right spot. In his video he set up a flying wing, which is a good first plane to build with INAV. His video was published on Oct 15, 2018 and is based on INAV 2.0 which is now out of date. Regardless, most of the information is still relevant.

INAV changes from time to time. Please notify Steve Schlesinger (INAV Fixed Wing Facebook Group admin) if you know of any changes or things that need to be updated or addressed. Our goal is to get you up and running with INAV as quickly and painlessly as possible.

While following this guide and using the INAV Configurator, be aware of one common mistake we have all made: Whenever you are finished with one tab and about to move to another, don’t forget to click “Save and Reboot”, or else your changes WILL NOT be saved!

CONFIGURATOR SECTIONS

SETUP TAB

Pawel’s video link to this topic: https://youtu.be/lkn9t7WBHNY?t=42
Importance: Medium
Difficulty: Easy

When you plug your flight controller into the USB lights will start flashing and hopefully you’ll get the USB sound notification. We’re going to assume you’ve flashed the board and you can log in. If you can’t do either, try using a port other than Com1. If you are still struggling, drop a message in the group and folks will walk you through it.

As you move the flight controller the graphic on the setup should show your flight controller moving in the same direction. The arrow on the board should point forward. If it doesn’t, don’t worry! Calibrating will take care of that. (We’ll fix that in the next tab) The indicators on the right all need to be green before the plane will arm. If your plane refuses to arm, this screen is a valuable resource in helping to tell you what’s wrong.

CALIBRATION TAB

Pawel’s video link to this topic https://youtu.be/lkn9t7WBHNY?t=46
Importance: High
Difficulty: Easy

This tab is where you teach your flight controller all the different axis’s. You don’t need to have the board in the plane to perform this step. It’s actually easier to do it when not in the plane. The arrow on the board points forward and should correspond to the direction on the screen. You can set the board on a table or other flat surface to help improve the experience. Don’t forget to save and reboot.

NOTE: A common problem for planes is that true level flight will have the tendency to push the nose down. Most planes can benefit from up trim of a few degrees. When you get to your first flight and notice that the plane tends to nose down in the gyro modes (Horizon, Angle, Acro), this is normal. A common ‘cheat’ is to place the plane on a table for step one and put batteries or something to take the nose up few degrees. This will fool the flight controller into thinking that level flight is actually with slight up trim. Another spot to do this will be in the configuration tab.

MIXER TAB

Pawel’s video link to this topic https://youtu.be/lkn9t7WBHNY?t=138
Importance: High
Difficulty: Easy

This is the portion where you tell INAV what type of plane it’s going into. The flight controller will do the mixing for you. Simply select the right plane type from the pulldown menu and click save and reboot. Most of the heavy lifting has been done for you with this move.

Important - If you have a delta, v-tail or some other custom setups in your radio, you need to turn them off. Kill your trim, kill your expo. THIS IS HIGHLY IMPORTANT!

PRESETS TAB

Pawel’s video link to this topic https://youtu.be/lkn9t7WBHNY?t=221
Importance: High
Difficulty: Easy

Chances are you won’t find an exact preset for your plane. Find something close. After you select it, you have to load the model and then click save and reboot. You can continue on to the manual process in step 9 if you want to do this manually (Not suggested).

PORTS TAB

Pawel’s video link to this topic https://youtu.be/lkn9t7WBHNY?t=243
Importance: High
Difficulty: Medium (People do get stuck here from time to time)

This tab is where you tell INAV what type of receiver you are using and where it is connected on your FC. The video does not spend much time here, because the settings will vary depending on your particular setup. If this is new to you, you’ll need to see Appendix 2 for instructions on setting up a receiver (RX) with your flight controller. As complex as this may sound, it’s as simple as finding where you physically connected your receiver to your flight controller (i.e. which UART you chose), enabling the corresponding INAV serial port for that UART on this screen, and clicking save and rebooting. Don’t let the word “UART” scare you. The USB ports you work with all the time are UART ports. The pins or pads you attach to dictate which UART ports you are to use.

This is also where you will learn if you need to buy a new TX/RX system. If you’re going to fly with a flight controller, you should have a system that takes advantage of serial-based receivers. Before you buy anything, watch videos and ask questions. FrSky uses OpenTX which has its own learning curve. There are other options in the market. Pick people’s minds in the group. Take your time and research your options. From this point on we’ll assume you have the radio system installed and working.

CONFIGURATION TAB

Pawel’s video link to this topic https://youtu.be/lkn9t7WBHNY?t=284
Importance: High
Difficulty: Medium/Hard (Pilots don’t always set up this tab as well as they could)

At this point, it is assumed your flight controller is working and is installed in your plane.

Go into the configuration tab and change the receiver (RX) mode to match your receiver's protocol (ppm, sbus, ibus, crossfire, etc.). Click save. After it restarts, go into the receiver tab and verify all controls are working correctly! You can do this by moving your TX sticks and verifying the corresponding movements on the various channels. If they are not working properly, you may need to change the Channel Map in your radio to AETR. The default on FrSky for some reason is RETA (Rudder, Elevator, Throttle, Ailerons). You will need to change this in your radio to AETR.

Side note: This is also a good time to check to see if you can calibrate your radio’s gimbals. My brand new FrSky radio wasn’t remotely close to calibrated. This is when doing a Google search is useful. Five minutes with YouTube and it was PERFECT.

Back in the configuration tab: change board and sensor alignment depending on how you have set it up in your aircraft. You want the model to be moving correctly when in setup tab, according to how you move it on the bench. Normally the arrow on the FC should point straight forward, but let’s say that your FC board won’t allow access to your USB plug with the arrow pointing toward the direction of flight. But if you turn it 90 degrees you have clear access to the USB plug. This is an example where you would tell INAV you have your flight controller facing 90 degrees one way or the other (this is the Yaw Degrees setting, and in this example it would be set to either 90 or 270 degrees depending on which way you turned your FC board). Performance won’t suffer because of this. You can even mount it upside down.

Under Esc/Motor Features, enable the motor and servo output and select corresponding esc protocol (standard etc...) and refresh rate. In the new INAV configurator the configurator will start to give you unsubtle suggestions if you go off track here.

Under Esc/Motor Features, the Servo refresh rate should be left at 50hz (99% of people use standard 50hz servos).

Under Esc/Motor Features, enable “Don’t spin motors when armed” (you want to be able to glide with no power). Also, select “0 seconds until disarm due to low throttle”. Leave min and max throttle at default settings if you want.

Under System configuration, select 256 Hz for your Gyroscope LPF cutoff frequency. It's the best possible option for a flying wing. Asynchronous mode should be disabled. Select flight controller loop time at 1Khz (doesn't really matter, but 1 kHz is a good value).

NOTE: (continuation of the note from the calibration tab) After setup, if when flying your plane you notice the nose pitching down during Acro, Horizon, and angle modes (and assuming you’ve gone through a normal level calibration in step 2), instead of recalibrating the gyro again, you can change the pitch in “Board and sensor alignment” section. There is no exact number to put in here to make your plane fly perfect. A good starting point may be 3 degrees. If it’s still nosing down during gyro modes, take it up a little at a time. You may need to repeat this process this a couple of times before you find the sweet spot. If the plane starts to stall at slow speeds, you may want to take it down.

Under Current Sensor and Voltage Sensor Battery Capacity, these are optional. Use them if you want and/or if your board supports it.

Under Other Features, permanently enable Airmode. Click Save and Reboot to save this step and all the changes you just made in the configuration tab. Don't forget to click Save and Reboot!!!!

We’ll be coming back to the configuration tab when working with the GPS.

SERVOS TAB

(We’re now going out of order when it comes to tabs. Some we won’t cover).

Pawel’s video link to this topic https://youtu.be/lkn9t7WBHNY?t=498
Importance: Medium
Difficulty: Medium

You will need to go to YouTube and learn how to perform a ‘High Five” test. You need to make certain all your control surfaces are going in the right direction. Often one or more servos is going in the wrong direction. This tab is where you reverse it. You can also tone down the rates here, but it will be across the board. This is more crucial for smaller planes that may not like full servo travel.

FAILSAFE TAB

Pawel’s video link to this topic https://youtu.be/lkn9t7WBHNY?t=594
Importance: Medium
Difficulty: Easy

If your plane doesn't have GPS, just leave failsafe set to "Land". The lack of a GPS unit means your plane has no idea where it is, so return to home (RTH) isn't even an option. This is why GPS units are highly suggested. In “Land” mode, the plane is going down where it lost signal. Make sure to set guard time for activation after signal loss to0!!

If your plane has a GPS unit, select RTH (Return to home) if you want it to come home. Click Save and Reboot.

TESTING

Please remove your prop! During testing the motor will spin up and the servos will activate. If you turn off the radio, the red parachute at the top of the page should light up indicating Failsafe has activated! If it doesn't light up, you may need to read your receiver/radio manuals on how to set failsafe, and then go and set it up manually so it will trigger correctly. If not able to do so, set it to trigger the "failsafe" mode under the "Modes" tab. Very important, don’t skip this step,

MAKE SURE you get the red parachute when turning off your transmitter! If it doesn’t light up, Failsafe has not activated and whatever action you selected for failsafe (i.e., RTH) WILL NOT WORK!!!

What you are doing is testing failsafe with this test. By shutting off the transmitter you are cutting the signal between transmitter and receiver. This mimics a real-world flight situation where you fly out of your transmitter's range. In reality, you never want to shut off your transmitter when your plane is in the air. We're teaching your flight controller what do if your plane loses signal.

Another scenario that pilots experience is when you lose video signal, but you still have a good control connection and can still fly the plane? This is where having a “NAV RTH” switch is important. (You will not see this option until your GPS unit is installed and working) If you lose video, you can flip on "Nav RTH" which is “return to home”. The video signal hopefully will come back as the plane comes back toward you, and then you can flip off the switch and fly normally.

PID TUNING TAB

Pawel’s video link to this topic https://youtu.be/lkn9t7WBHNY?t=658
Importance: Low
Difficulty: Medium/High (You really need to have some time with INAV under your belt before messing with the PIDS on your own).

This tab is where you go to fine tune your plane after your maiden flight. You don't need to do this if you have selected a preset in step 4, but it’s a good idea to go over the settings of your preset just to learn what they are.

These are instructions for manually setting up your plane, if a preset from #4 isn’t used. If you’ve used the preset, you can look around a bit but you’re not required to change anything.

Leave all PIDs at default values for the maiden. If you want, you might slightly increase the pitch I (Integral) to 12 and roll I (Integral) to 9.

ROLL rate for flying wings up to one meter wingspan should be around 300 - 400. PITCH rate for same wingspan should be around 120-200 (select 120).

Select the ROLL and PITCH angle, they should be around 40 for ROLL and 30 for PITCH.

Gyro LPF cutoff frequency should be around 30-40, that makes it smoother when it gets hit by winds/gusts and tries to self-right itself or fly in automated modes such as PosHold and RTH.

Leave all the rest (D-Term, D-Term Notch, etc. and everything in Miscellaneous) at default values. However, TPA should be around 0 for maiden, you can tune this after the maiden.

Don't forget to click Save and Reboot!!!

ADVANCED TUNING TAB

Pawel’s video link to this topic https://youtu.be/lkn9t7WBHNY?t=952 Importance: Low
Difficulty: Medium/High (Some values are safe to change, but use cautiously).

If you don't use GPS and automated functions, leave everything AS IS.

Note: There are different sections in this guide dealing with Advanced Tuning. This one is for non-GPS users. We will be dealing with the Advanced Tuning Tab later.

MODES TAB

Pawel’s video link to this topic https://youtu.be/lkn9t7WBHNY?t=977 Importance: High
Difficulty: Low/Medium (Don’t setup modes you don’t understand).

Frankly, this is a subject that is too broad to cover in this document. We’re working on a second set of documents to cover all of these modes. The most important thing is to understand what each mode does before you assign a switch to it. It’s really in your best interest to start with the basics and then add more modes over time.

Another important point: If you don’t have a working GPS, some modes won’t appear. This isn’t very well documented. For example, if you want to see NAV RTH and NAV Cruise modes, you’ll need to have your GPS setup.

The key modes you’ll want to get started with are:
Arm, Angle, Horizon, Nav RTH

NOTE: LOOK IN THE FILE SECTION IF YOU HAVE A FRSKY TARANIS SYSTEM. WE HAVE A COMPLETE BUILD WITH MODES ACTIVATED. YOU CAN IGNORE THIS SECTION.

Other modes like Autotune and Servo AutoTrim can make a huge difference with your plane. Servo AutoTrim will get the plane flying remarkably better if used properly.

Just as important as learning the modes is how you position them on your switches. After setting up your first INAV plane you’ll have more modes to remember. If your switches are in different locations for each plane, you’ll be asking for trouble. The French have a culinary term “Mise en place.” It means “everything in place.” When a chef is busy, they need to grab for something, and it needs to be in the same spot every time. So, everything is set exactly in the same place, all the time. It has to be something that is logical to you, and that you can memorize. Over time you can add new modes to unused switches.

The first time you work with your radio, your switches won’t work. Even with the most basic FlySky transmitters you’ll need to assign a channel to a switch. Once again, there are great videos on YouTube to teach you this.

Pro Tip: Perhaps you have a transmitter with a limited amount of switches and channels, but it has a couple of knobs. And let’s say you only have a six-channel receiver, with 3 channels going toward your delta wing. The FlySky/Turnigy for example only has one 3-way switch. You can assign a lot of modes on the knobs. You can have the three-way switch work the Arm and Nav RTH. If you use the knobs and watch the modes on your OSD you can scroll through perhaps five modes per
knob. For example: One knob could have manual, angle, horizon, and Nav Cruise, while the other knob could have your 3 OSD screens, Servo AutoTrim and Autotune. In this example you would have 11 modes on 3 channels.

OSD TAB

Importance: Medium
Difficulty: Low/Medium

As you can tell, there are many things you can put on your OSD screen, but how much do you really need? It’s easy to flip on everything, but the screens do get crowded. Thankfully you can now have 4 different OSD screens! You need to go back to the “Modes” tab to set up changing screens with switches or knobs. If you have no use for a knob (such as a flying wing) here’s a chance to set up the four screens plus “OSD Off” on a knob. Here are some ideas that experienced INAV member Marc Hoffman came up with.

Examples:
Main screen (Default screen) - If you have nothing else on switches/knobs this will be your only screen. Mark uses this screen to display any and all relevant information.

1st screen (Standard flight screen) - Marc removes the GPS coordinates and throttle views, and adds a map view.

2nd screen (Freestyle flight screen) - Marc’s uses only minimal information such as RSSI and battery voltage.

3rd Screen (Tuning screen) - Marc turns everything off on this screen for temporary use of auto-tune and activating PID values in the OSD.

You can also use the “OSD off” switch if you have a need for no OSD whatsoever. The OSD on a knob works great, you should try it.

LED TAB

Importance: Medium
Difficulty: Low/Medium

If you are using an LED strip, you first need to enable that function from the configuration tab and Save and Reboot. Then go to the LED tab and set up your programmable LED strip according to your liking. Click Save and Reboot.

LED’s are something that we picked up from our drone brothers. They find it helpful to see the quad, and to know what their orientation is. If you do a lot of flying at dusk or dawn this may be useful. There are LED’s with beepers that are inexpensive and not too difficult to install. This is something you can check into as you get deeper into INAV.

One idea from our moderator Jason is to set the LED to come on when the plane is armed. Many LED’s are sold with beepers. You can also set the beeper on a switch, which comes in handy when you lose your plane. Provided you are close enough, you can simply turn it on to hear where your plane is.

CLI TAB

Pawel’s video link https://youtu.be/lkn9t7WBHNY?t=1082 Importance: Medium

Difficulty: Medium/High

If you have really bad CG and/or Servo throw problems, you can change the I-term servo throw limit to 300. The new 300 I-term throw limit will help with the Auto-tune process.

Here’s how to change it to 300: In the CLI Tab, type "get iterm" and press enter. Note what the Iterm Servo throw limit is (default is 165). Now type "set fw_iterm_throw_limit=300" and press Enter. Now type "get fw_iterm_throw_limit" and press Enter to check if it correctly changed to 300. Finally, type "save" and press enter.

After performing a Servo Auto trim and Autotune correctly as suggested above in step 11, come back here and set the I-term Throw limit back to the default 165.

Keep reading below this point if you want to use GPS, Automated Flight Modes, etc

A few notes about GPS, Barometer and Compass (Magnetometer)

For automated modes, if you have a barometer on your flight controller, leave it enabled (blue icon should be lit up on top) and USE IT since GPS altitude accuracy is not very accurate. Also, new to INAV 2.1, you can use a magnetometer on fixed wing airplanes. This is a compass. Up until this release we didn’t use it. You are not required to have a magnetometer to use flight navigation on INAV. GPS units without a magnetometer are often less expensive.

GPS TAB

Pawel’s video link https://youtu.be/kSs3JYT5Zns?t=177
Importance: Medium

Difficulty: Medium (People get stuck here from time to time)

GPS setup can be tricky the first time around, but the newer GPS pucks and latest firmware releases have made it easier. It’s actually quite simple in theory. There are four wires if you’re using a GPS. Power, ground, TX and RX. The RX wire goes to the TX port on your flight controller. The TX from your GPS goes to the RX port on your flight controller. The little clue that they will give you is that the board will say something like TX3 and RX3. The “3” means you are using UART 3. In the Ports tab you simply enable the GPS peripheral for the GPS on UART 3, then click Save and reboot.

And yet, it’s rarely that easy. See Appendix 3 (Getting your GPS Working)

Here are the notes from Pawel’s video on GPS:

M8N series GPS are highly recommended. He suggests the BN-880 or the BN-220 (My favorite GPS) and the Matek GPS.

For GPS setup, first go to the Ports tab and enable GPS on the corresponding UART and also select the correct baud rate (if you know it) or select Auto-Baud. In most cases Auto-Baud will work. Click save and reboot.

Now, go into configuration tab, select “Enable GPS for navigation and telemetry” and select the correct protocol for the GPS you are using. Select “Ground assistance autodetect” or depending on where you live, select the appropriate setting. The declination is not needed if you are not going to be using the magnetometer. Again, click save and reboot.

To see if GPS is working properly. Check for the blue icon on the top of the page, then go to the GPS tab and check to see that there are no errors and time outs and that communication is normal by looking at the message count (it should be rising).

ADDING GALILEO

Pawel’s video link https://youtu.be/kSs3JYT5Zns?t=528

Adding Galileo can greatly increase the number of satellites you have, and the more the better! More satellites mean more accuracy, and hopefully less time waiting for a 3D lock in order for INAV to arm.

Note: Pawel explains that Galileo is only for Europe and that you will not have good results in North America, however many INAV and Betaflight users are using Galileo in North America with great results. It’s simple to change this setting to on using the CLI tab, so why not try?

Go into the CLI tab and type "get gali" and press enter to see if it is off or on. Type "set gps_ublox_use_galileo=ON" press enter, and then type "get gps_ublox_use_galileo" and press enter to see if it saved to "ON". Now type save and press Enter.

ADVANCED TUNING TAB

Pawel’s video link https://youtu.be/kSs3JYT5Zns?t=577 Importance: Medium

Difficulty: Medium/High

- Leave Position Estimator as is
- Ignore Multirotor Navigation Settings

Under Fixed Wing Navigation Settings:

- Cruise throttle, min and max throttle settings will depend on your aircraft, you should know how much you need to cruise and not stall, etc.
- Max bank angle (used in all automated flight modes) is set to 20. That will make for very wide turns. You should increase it to 30-40.
- Dive angle - leave as is
- Climb angle - leave as is or change only if you know your craft is not underpowered and can climb on a steeper angle.

- Pitch to throttle ratio is how INAV uses the throttle when in automated modes, lower it if you see the craft is applying too much throttle when climbing, increase if it doesn't apply enough throttle while climbing, causing a stall. Consider tailwinds and headwinds for this setting. Usually, leaving this as-is will be ok for most planes that aren't severely underpowered.
- Loiter radius is preset to 50m radius circles. You can change this if you want a tighter radius but remember your wing might or might not be able to make a tight radius. Change the bank angle to be able to achieve a tighter radius.

RTH AND LANDING SETTINGS:

- Select "at least" for RTH altitude mode - The plane will climb to that altitude.
- Change the RTH Altitude as you like: Default is 10m (1000cm), it is recommended to increase it since you are flying a fixed wing. 30-40m is good (3000-4000cm).
- Climb before RTH should be off for fixed wings, because if you leave it on, it will first climb and only after it reaches your RTH altitude it will turn around to go home! If you leave off as recommended it will turn around right away when RTH is called (we want that) and then start gaining altitude as it flies home.
- Climb regardless of position sensor should be disabled.
- Tail first should be disabled.
- Land after RTH depends on what you want:
- "always" will descend slowly in circles with intent to land, every time you go into RTH. Make sure where you are flying there is enough space to do so. The plane will land (crash gently) into the ground.
- "only on failsafe" will do the above, but only when there is a failsafe state. For example, if you fly out of transmitter range or your transmitter runs out of battery or you have a radio problem. In this mode the plane will not land if you enabled failsafe on a switch.
- “Never” will never try to land the craft after it comes home. It will fly in circles above until the battery dies.
- “Only on failsafe” is recommended and has saved many planes when people had radio problems.
- If you decide to use "only on failsafe" - Leave vertical landing speed at 200. Change min vertical landing speed at altitude to 1500cm or 1000cm (15m or 10m). This is the height at which the plane will cut the motor and try to land softly.
- Leave all other numbers below as is.

Now you are done with the advanced tuning tab. Click save and reboot.

NAVIGATION MODES

Pawel’s Video Link - https://youtu.be/kSs3JYT5Zns?t=1109
Importance: Medium
Difficulty: Medium/High

Now we return to the modes tab to set up the navigation modes. You will not see these modes if you don’t have a GPS unit enabled.

The most important automated flight modes are "nav althold" and "nav poshold" - these two modes should be used simultaneously and together on the same switch. “Nav RTH" – use this mode instead of the “failsafe” mode. It is also recommended to use "nav launch" as mentioned before, to assist with launching! After you are done don’t forget to click save and reboot.

For more info on all the modes, go to the iNav website https://github.com/iNavFlight/inav/wiki/Flight-modes

SIDE NOTES

ASKING FOR HELP

Please feel free to address questions in the discussion portion of the INAV Fixed Wing Group. When you do, please be specific as to what plane you have, which flight controller, which version of INAV you’re running and describe the issue in detail.

GAUGING SUCCESS

This is a journey. Deciding to put INAV on your plane is the first step. Next will be flashing your flight controller for the first time. Then getting the receiver working. What will be exciting is the first flight. It may not be as smooth as you hope. You’ll probably need to do some tuning. When the plane is auto trimmed, you’ll be better off. Then you can start investigating how to fine tune the PIDs.

The INAV developers have taken a lot of the guesswork away. Still, there will be more refinements along the way. This is an exciting time for INAV, and each new version is something to celebrate. It’s looking like INAV will be able to do some fairly advanced calculations in real time with a large number of variables. What this means is that INAV will be able to give a better flying experience than anything you’ve ever experienced before. Hopefully soon the setups will be even easier, and the learning curves won’t be as steep.

INAV isn’t perfect. It’s an emerging technology. You are now a part of it during its rapid development phase, prior to going mainstream. It doesn’t get much more exciting than this!

HOW OFTEN SHOULD YOU UPDATE INAV?

Even when you get good at flashing your board and going through the steps, you’re still looking at least an hour to get back to where you were. Sometimes compelling new features are added and that hour or so is a small investment compared to the benefits you will get out of it.

When you flash your board, INAV will give you the option of the most current stable release by default. You can click on the “show unstable releases” and get to see the optional release candidates. In the INAV Fixed Wing Group we often discuss these release candidates. The trade-off for being the first to get a sneak peek at what’s next is that sometimes, some of the new features aren’t fully baked. You can go to the Github INAV site to see known support issues prior to installing the INAV release candidate firmware on your flight controller.

A good rule of thumb is your plane should be updated with the most current stable version of INAV that your fight controller will accept about once a year if you don’t fly it often, and about twice a year if you do fly it often.

As you work with your settings and learn more about INAV, you’ll need to connect your FC to your computer from time to time. Whenever you build, make it a priority to allow access to your USB plug on your flight controller. Be careful when installing your USB cable to your USB plug. These plugs are known to break off easily (another reason to make access easy, to avoid forcing things).

APPENDICES

Appendix 1 – Flashing INAV on your FC

This video covers how to not only flash a flight controller, but how to set up INAV. He’s showing it on version 1.9, so some things have changed since it was made. It is also a review of how to setup a Matek F411-Wing, which is a great FC board.

https://www.youtube.com/watch?v=7J80880pTDs

There are better videos but some of them are getting too old to share.

Appendix 2 Setting up the receiver to flight controller

This video explains the different receiver protocol types. You really should watch this, especially before you buy a new receiver. Also, since it is from 2015, it doesn’t mention Crossfire, which is a very popular transmitter / receiver system, especially for mid-range or long-range flyers.

https://www.youtube.com/watch?v=GbUMC8h2uhU&t=197s

This video moves slowly, explaining how to hook up your receiver to your flight controller.

https://www.youtube.com/watch?v=wSdX758qfpM&t=68s

Appendix 3 - Getting your GPS Working.

So. let me guess, your GPS isn’t working? We can help you figure your problem out 98% of the time. The most common problems are:

1. Power - The GPS works from 5V and the vast majority have an indicator light of some kind. No light means no power. So, what are the common issues that cause a lack of power?
a. Your flight battery isn’t plugged in - Many FC’s need a flight battery plugged in to provide power to the GPS unit. If you are still powering the FC from your USB port it may not be powering the GPS. So if you’re setting up your flight controller prior to install and the GPS isn’t powered, you’ll have to wait until you’ve got full VCC power before setting up the GPS.
b. You’ve plugged into 12V - Your GPS unit is fried. This isn’t all bad. The place that will sell you a new GPS unit will also sell you a 5v BEC and a multi-tester. Time to move on.
c. You got a dead unit from a friend or took it from a crashed plane - You’re not the first guy to salvage parts from a dearly departed plane. Sometimes the crashes are a bit too much for the GPS units. They are often resilient, but they have been known to break due to a bad crash. Sometimes your buddies will unknowingly give you their dead gear. GPS units aren’t that expensive, so just buy a new one that works.

2. Wiring/Connection - GPS units have simple enough wiring, so taking a few minutes to check out wiring diagrams will save you problem in the end. Wiring and connections are often problems for GPS units.
a. Red goes to +5V, black goes to ground - We’re just focused on these two wires. You need to be certain that you look at the diagram of your GPS unit. Sometimes it says VCC, and other times it says +5. The red and black wires don’t always sit next to each other on these units. On the BN-220 for example, the red and black wires are on the ends with two other wires between them.
b. JST Cable is backwards - Speaking of the BN-220, it comes with a micro JST cable. Look carefully – on one end the red and black wires are next to each other, this plugs into your flight controller if you have the right plug. The other end (where the red and black wires are on the opposite ends) goes into the GPS.
c. Poor connection - Someone in our group wrote recently about losing a Bixler due to a faulty GPS connection. He used pins instead of soldering in wires. Some pins are better than others. I find the right-angle pins to be a bit beefier and less likely to break. I have broken cheap straight pins before. If you really want to be certain of a good connection, get some good 20AWG silicone wire, and connect those wires directly to your board. Then run +5 from your BEC. Make certain to check to see that your connection has solder on the wires and flows down to the base where it goes in the hole. If you are running your GPS further out on your plane’s wing and have run a long wire that you have soldered, check to make certain the connection is good. You will need high powered magnification to check this out.
d. Wrong wires / backwards wires for TX and RX. Not all the GPS units tell you what the wires do. On the older hockey puck style GPS units, you’ll need to open the case and look for the wiring diagram. They have the compass as well. You need to write down the TX and RX wire colors. The GPS TX wire goes to the FC’s RX pin. And the GPS RX wire goes to the FC’s TX pin. The other two wires (if you have them) are for the compass.
e. Wiring too close to power fields – Power distribution boards, BEC’s, FC’s and Video transmitters create small magnetic fields around them (especially high powered video transmitters). GPS units and especially compasses (magnetometers) are sensitive to these fields. If your GPS unit, compass, and/or wiring are too close to these components, it can disrupt the signals enough to prevent the GPS or compass from working properly. When building your plane, try to locate the GPS unit, compass, and wiring with some clearance around these components.

We are now assuming you’ve got lights working on your GPS, and that they stay on.

3. Ports - Wherever you connect the GPS wiring on your FC board, there is a UART assigned to that port. You need to assign the GPS to that UART. Go into the Ports tab and click on the correct UART for your GPS unit. Often you’ll find wiring diagrams that show which set of pins is suggested for the GPS Unit. Make sure the GPS RX and TX wires are connected to these pins. There should be a number like TX6 which means in the Ports tab you click on the GPS in “sensor” section for UART 6. You don’t need to hook up any other wiring. Check your GPS unit specs to see the maximum baud rate for your GPS. In the Ports tab, set the baud rate to that, or lower (a lower number). Click save and reboot.

4. Protocol - This is after you get the lights on the GPS working. After you have configured the port correctly, you need to enable GPS in the Configuration tab. Make sure “GPS for navigation and telemetry” is turned on. Under protocol, make sure you have selected the correct protocol for your GPS unit. This can be tricky. The best place to get this information is from the manual for your unit, but sometimes you need to go to the website you bought the GPS from or search the internet for more information. For “Ground Assistance Type”, pick the one that best works for where you live or is closest to where you live. For “Magnetometer Declination (deg)”.
5. INAV Flash Problems

Still not working? On rare occasions, a board flash isn’t as successful as it could be. It seems to work fine, but certain things don’t work. Sometimes GPS is one of those things that just doesn’t work no matter what you do. When you re-flash your board again, this time do a cold reboot of your PC, make sure you are using a quality cable, and plug your USB cable directly into the computer (not into a hub). Don’t have other programs running, and don’t open other screens while flashing. This all may seem a bit extreme, but the idea is to eliminate all potential sources of an unsuccessful flash. Experience has shown these steps really do work.

Another time you may experience issues with GPS is at the field. If you get your GPS unit working but your plane isn’t arming, try this: Unplug your flight battery, make certain your radio is on, but the ARM switch is off. Then, plug in your flight battery and stand at least 10 meters back from your plane with your radio in hand. Give it around 90 seconds and try and arm again. You may also want to double check that your plane is level.

After all of this you should get a blue GPS Icon. If it’s red, that means the GPS isn’t talking to the flight controller. If it’s red then blue then red again, don’t worry.

a. Take the plane outside, plug it in and let it spend a few minutes finding GPS for the first time. If you came back inside and hook the plane up quickly. You may need to use a laptop to check and see it’s seeing the satellites.
b. The GPS unit should be on your wing pointed the right way up toward the sky.

Appendix C -Getting Started with INAV

YES, YOU CAN DO INAV.

INAV has a steep learning curve. If your current RC building experience is with multi-rotors, you have an advantage, because you know about flight controllers and flight control firmware. If you’re experience is with line-of-sight fixed wing aircraft, you already know about airframes and will need to learn some electronics and how to work with INAV. Regardless, if you have the will, the INAV Fixed Wing Group on Facebook is a community that is behind you. So yes, you’re not alone.

Our advice for learning INAV is to not force things. Take your time, lurk around on the group page, read the discussions. Watch the videos. The “Units” section is loaded with past discussions we’ve highlighted to help bring certain things to your attention. The Candy Shoppe is full of cool things that people have done with INAV, including builds, mods, and great flights. We hope it will be an inspiration to you!

When you build your first plane, resign yourself to the notion that it won’t be a fast build. Enjoy the journey because you’re only new once. The next build gets easier. The more you invest up front the more rewards you’ll recoup over time.

YOU WILL NEED TO BUY STUFF

You will need to buy flight controllers, video transmitters, FPV cameras, goggles (or monitor) GPS units, soldering supplies and perhaps a whole new transmitter radio and receiver if you don’t have them. This will be an investment upfront. But, once you’re past it, the money outflow drops considerably. Once you get your first INAV plane dialed in, you’ll be excited for your second and third builds.

First, a few words of advice about buying flight controllers (FC’s). Not all FCs are supported by INAV. More importantly, there are a lot of clone knockoffs out there. It is crucial to follow this document (https://github.com/iNavFlight/inav/wiki/Supported-boards) which contains the current list of supported FCs. Using this link to purchase your FC will ensure your FC isn’t a clone, plus INAV gets a small part of the sale which helps to fund INAV development. Why not buy a clone? One example is a common problem with the 5v supply. One of our members lost a $400 (US) plane with a clone of a Matek F405-Wing FC. There are lots of other good reasons as well. When it comes to flight controllers, Matek seems to be the leader, followed by Omnibus and the Furious FPV line. HGLRC recently came out with their first FC for wings.

Electronic components typically have many options in different price ranges. Generally, you get what you pay for. When it comes to radio systems, don’t be cheap. Buy something that will meet your needs, and maybe a little more. Don’t be impulsive. Study the guides in this Facebook Group. Read and listen to the advice of others who have paved the way. A lot of us fly with FrSky, FlySky, Spektrum, TBS Crossfire, RadioLink, Dragonlink, EZ UHF, Futaba, TX and RX.

IS YOUR PLANE REALLY FLIGHT WORTHY?

If you don’t know how to fly line-of-sight, it’s best to reach out to someone who understands how to do this and have them help you. Ask them to inspect your airframe. If they are knowledgeable, they will check the CG and make certain your servos are mechanically centered with the proper amount of deflection with zero trim. There is a difference between a plane that just flies, and one the flies well. A flight controller won’t completely compensate for a poorly built plane. Thankfully there are many great build videos online. Get your plane’s CG properly balanced and make sure that your flight controller is positioned as close to the CG as possible.

We are also assuming you have secure electrical connections. If you’re new to soldering please triple check your solder joints under high power magnification. Troubleshooting electronics can be challenging and having confidence in your connections makes it much easier. More importantly, poor solder joints have been known to cause crashes. A good solder connection should touch the pins and board without touching other pins. Start with a good quality soldering iron and good quality solder. Spend a little time studying soldering techniques, how much heat to use, etc. This is a skill you get better at over time and having good quality tools will make this process much easier! 100% secure electrical connections are mandatory for your success. Take your time and do this right. You have a lot counting on this.

FLASHING INAV TO YOUR BOARD

When you build your plane keep in mind, you’ll need access to the USB port on your flight controller. Why? Well, because, sooner or later you’ll need to flash INAV to your board. The question becomes how often do you plan to update INAV and how easy is it for you to get your USB port hooked up to your computer? Some boards come pre-loaded with Betaflight, or you may get a board with an older version of INAV, and you may want something a bit more current. Also, INAV will undoubtedly be updated in the future, and you may want to take advantage of new features.

The best time to flash the board is when you first pull it out of the package, before you install it into the plane. One advantage to this is if there are any defects in your new board, you will know before you spend a lot of time installing and soldering. Not only can you flash the board before it is installed, but you can run the first few steps of the board setup without it being powered by a flight pack. The USB connection will power the board. See Appendix 1 for flashing INAV.

Assuming you have everything built, ready and connected correctly to corresponding ports, you can now follow the steps in this Study Guide to get your plane flying amazingly!

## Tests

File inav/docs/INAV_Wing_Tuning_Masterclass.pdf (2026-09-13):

This manual and the contents within are the intellectual property of the INAV Fixed Wing Group. © INAV Fixed Wing Group 2019, All rights reserved.

# INAV WING TUNING MASTERCLASS

by Marc Hoffmann
Editing and color commentary by Steve Schlesinger

TABLE OF CONTENT

FROM THE FACEBOOK INAV FIXED WING GROUP

The INAV Fixed Wing Group is a friendly support group for INAV fixed wing pilots. It’s a place to go for answers, ideas and inspiration. When the group first started there were more questions than answers. People struggled with getting INAV setup properly for their planes and didn’t understand how to tune the plane nor what all the modes did. We created a series of manuals to help people walk them through the process of basic setup, trouble-shooting, we covered all the flight modes including Nav Autolaunch and then Masterclass tuning of INAV.

By taking many surveys of the group we discovered that many members were using FrSky transmitters and receivers. Taking on OpenTX while learning INAV was a bit too much of a task to take on all at once. After many surveys with the group we created an FrSky radio setup that is simple, intuitive and covers all the INAV flight modes and enough features that you will not outgrow it quickly. Everything works exceptionally well and there are is a very complete manual that comes with it. This download is available to you in the files section INAV Fixed Wing Group’s Facebook page.

The reason why the INAV Fixed Wing Group is so friendly and enthusiastic is because we get you. INAV fixed wing isn’t plug and play and there is learning, reading, and failures along the way. The success is so strong, so sweet with INAV fixed wing that this is something you’ll just love. In the end, it’s all worth it. You’ll want to keep going, to keep learning, to keep pushing yourself to do more. Read, learn from your mistakes, accept your failures and never, ever give up.

Because the INAV developers have supported the fixed-wing community so well (Thank you!) , we’ll keep going with these manuals. A list of the most up to date resources can be found at www.bit.ly/INAVFWG

INTRODUCTION

As many of you already know, our INAV builds are not just plug and play. Like on multirotor, any wing model has its own behavior, characteristics and moods… Let’s call it personality. To get a plane flying as well as possible, INAV needs to learn what to do in any situation. This tuning process is necessary to get a plane to fly in a way you are proud of and want to show to your friends.

Before starting with this tuning guide, you need to prepare a few things. First of all, you need a plane that is already completely set up. All final hardware needs to be installed, the correct battery in use, all your modes are configured, the mixer is set up correctly and you already did a maiden flight at least in manual mode to see if all works fine. If this is not the situation right now, look in our other guides first to get your plane ready. The best way is to start with the INAV Fixed Wing Setup Guide (https://docs.google.com/document/d/e/2PACX-1vQgUTqTQMVMGl3_nl_SGA_JPy-nEscJk_FeAZxMdeRSfFiEVN5LwgFdAb-mDpx6EXfNVUdmutEzXzQs/pub) from Steve and Georgios. If you are able to understand German language, then you can also follow my First setup tutorial on YouTube. (https://youtu.be/l51Ps2nSWzQ)

This Guide will consist of three major phases. Phase one will be the initial tuning with Autotune to get a nice and stable flight in calm conditions. Phase two will be a manual fine-tuning tutorial, to get the plane ready for windy and gusty days and optimize it for different speed situations. In phase three we will go into some special features and optimizations to get automatic modes work perfectly.

So, let’s get started!

PREPARATION

To get through the whole tuning process, the following conditions need to be met and some modes need to be set up on your transmitter and INAV. If you are new to INAV and use a Taranis Q7 or a X9D, it is recommend for you to use our Beginners Setup Profile from Darren Lines. (https://lookaside.fbsbx.com/file/INAV%20Fixed%20Wing%20Group%20-%20OpenTX%20Model%20Manual.pdf)

NEEDED HARDWARE

- Working GPS Module (Compass optional but not recommended)
- Active Blackbox with On-Board Flash/SD Card or alternatively FPV Recording

NEEDED MODES

- MANUAL (for maiden and emergency reasons in case of a failed or bad tune)
- ACRO / RATE MODE (active if no other fly mode is activated)
- ANGLE
- NAV CRUISE + NAV ALTHOLD (to easily tune board alignment and optimize navigation in phase three
- NAV RTH (optional)
- NAV POSHOLD (optional)
- AUTOTRIM
- AUTOTUNE

PHASE ONE: INITIAL TUNING

If you did not maiden the plane before this point, that’s no problem. If your CG is correct and all hardware is tested on the bench before, you can do the maiden right now. Make sure you do the maiden with Manual Mode active via a switch and do not use Autolaunch. Get someone else to throw the plane so you have full control over the launch. If you have already maiden your craft, just skip the next step.

GETTING AIRBORNE AND TEST THE BASIC TUNE

After your plane is in the air in manual mode, make a few turns and see if all goes well. The next step is to see if the default PIFF values can keep the plane in the air without getting unresponsive or ‘freaking out.’ The best thing to do this is in FPV mode but Line of Sight is fine too.

Fly to a safe height and disable MANUAL mode and make sure no other mode is active (ANGLE, CRUISE, HORIZON etc.). Continue flying around and watch the plane and be ready to switch back to MANUAL if the plane behaves strangely. Maybe the plane will feel a bit sluggish now or it could also happen, that it starts to oscillate on one axis. In the second scenario, switch back to MANUAL and leave the stabilization disabled for now. The plane can stay in the air for the next step but after landing, lower the P and I values in PID Tuning Tab and try again before continuing. You can use the trim on your radio at this point but only if you stay in manual mode. Do never use radio trim on any stabilized flight mode!

DETERMINE THE PHYSICAL LIMITS OF THE PLANE

To be able to control the plane correctly, INAV needs to know the physical limits of the plane. Four values are essential: roll rate, pitch rate, yaw rate and stall throttle. The easiest way to get these values is, by recording your flight with an on-board camera or an FPV recording. If you only do LOS flights without camera equipment, you can also use Blackbox data to analyze the rates. To do the test, just follow these steps. If you are a beginner pilot, you should let a experienced pilot do this for you because it needs some extreme maneuvers. Activate the Roll and Pitch angle view in OSD to use them as a reference when calculating the rates later. Also, the Throttle Value should be activated in OSD.

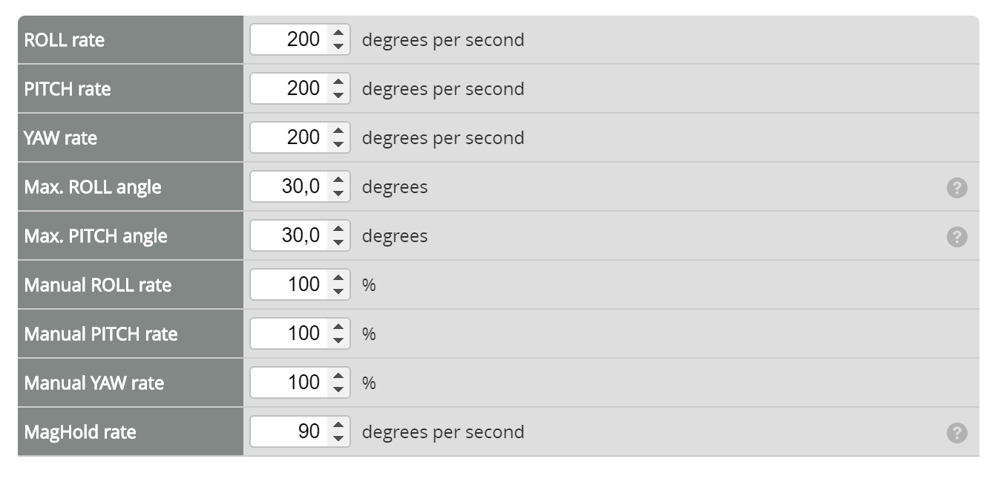
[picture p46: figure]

It is essential, that this is done in manual mode and at medium to high airspeed.

ROLL RATE

Fly level at a high airspeed. Do some roll maneuvers at quick and full stick deflections. On agile planes you can even do a double roll to get best results. On big planes and cruiser builds like a Mini Talon or an S1100, you should not do full rolls but hard left and right banks to more than 45 degrees on each side.

PITCH RATE

Fly at the same airspeed as before. Then go into a short dive with about 45° nose down and instantly pull back on the pitch stick to maximum deflection and do a loop. On bigger wings or planes that are not able to do a loop, just do a nose up to 45° and then level out again. Do these two or three times to get an average.

YAW RATE

If you fly a plane with V-Tail, Rudder control or differential thrust the Yaw Rate needs to be measured too. Fly level first. Then input a full Yaw deflection and at the same time use your Ailerons in the opposite direction to keep your wings at only a slight bank angle. Do at least a 90° turn or better a full 360° Circle this way

STALL THROTTLE

Fly level again. Then lower the throttle very carefully, further and further, in small steps and try to keep the plane at the same height. If the plane becomes unstable, loses height or pitches nose down, raise the throttle again. This way you determine the minimum cruise throttle to keep the plane in the air and a value to set for automatic throttle modes. This needs to be redone if you build additional equipment into the craft, because stall throttle will raise with more weight.

CALCULATE THE RATES

After doing these maneuvers, land the plane and get to a PC. If you recorded your FPV feed with the active OSD elements, open the video file with VLC player or any media player that can do a frame by frame stepping of videos. For Pitch and Roll rates, look at your video and search a point, where your maneuver already has reached its maximum speed. Write down the angle shown in the OSD and skip frame by frame while counting them. If you did a full roll or loop, just count the frames of half of the maneuver. For rolls start counting the frames when the OSD shows 90° Bank Angle and stop counting the frames on -90°. For Pitch start at 0° pitch and stop at 180°. For Yaw you count the frames depending on compass position and a 180° turn. Then calculate each rate by the following formula.

((360° / measured angle) * counted frames) / FPV frames per second (24 PAL/30 NTSC)

The result is the rate in Degree per Second. Set these values in the PID TUNING tab in INAV configurator. Better set these slightly lower (by 10%) but never set them higher!

To get your safe cruise speed, look at your OSD during your stall test. Write down the throttle value when the plane starts to descent or pitch down or even stalls. Add 20% throttle to the shown value to get your minimum cruise throttle for lowest safe speed during navigation. If the shown throttle was 40%, your safe cruise throttle value would be 1480 in configurator. You can set this in the Advanced Tuning Tab.

AUTOTRIM

After setting these values, the next step will be trimming the control surfaces. If you used radio trim before, you must reset the trims to zero at this point. Never fly with active radio trim when in any stabilized mode. Also, this needs to be done in very calm wind conditions.

Launch your plane again. You can do the trim in ACRO mode, but I recommend using ANGLE mode at this point to let INAV stabilize the plane and determine the trims by itself. Fly with a comfortable cruise speed, but not close to stall and not at full throttle. Fly in a straight line and keep your fingers off the sticks, then activate AUTOTRIM via switch and keep it activated. Wait about 5s before taking over control of the plane again. Switch back to your desired flight mode, land and disarm the plane. Now the trim is saved.

In disarmed state, switch back to manual mode and look at the control surfaces. Measure the deflection of each surface or just take a picture. Go to configurator und switch to the Servo Tab. Look at the midpoints of each servo. If the midpoints are in a range between 1450 and 1550, you are done. If the values are lower or higher than these, you need a mechanical trim to avoid losing servo authority. To do this, reset the midpoints to 1500 and then mechanically move the pushrods to get the servos in the same position as you have noted before.

Then do another AUTOTRIM flight and check the midpoints again. All midpoints should now be close to 1500 and you are finished here.

AUTOTUNE

Now let’s get into the serious stuff. After a lot of preparation, INAV will now finally learn how to control and stabilize the plane in a smooth and reliable way. For AUTOTUNE you need to fly in calm conditions with ideally no wind at all. For windy conditions, this needs some manual adjustments. We will do this in Phase Two.

Start flying around in ACRO mode. You could also use ANGLE mode, but this is not recommended because it is not possible to do very sharp maneuvers here to do a good tune. Alternatively, you could use HORIZON Mode to keep the security of self-leveling. If you don’t want to do these maneuvers for yourself because you don’t have enough experience, ask an experienced pilot to do this for you.

Turn on AUTOTUNE in flight via switch. When doing this the first time, the plane will likely become very sluggish. Immediately start doing hard roll and pitch maneuvers with full stick deflection in each direction and quick stick centering. The craft will become more stable quickly after a few maneuvers.

Do this always at a low speed, especially if your Motor setup is very powerful. This method will calculate the PIFF controller values depending on the airspeed and control authority you have. If fly too fast, the plane will become sluggish again at low speeds or at landings. So lower speed is better and high-speed tuning will be done in Phase Two.

Do the AUTOTUNE as long as you want. Tip: Add an OSD Layout with ROLL PID and PITCH PID activated to see how the values change in FPV, so you can see when the tuning is done.

As soon as the tuning is done, disable AUTOTUNE via switch and land the plane. DO NOT DISARM after landing. Turn on AUTOTUNE again. Then move both sticks down and outwards (left stick down and left, right stick down and right) for about 2 seconds to save the new values, then disarm the plane. You can then check with the configurator if the saving has worked.

PHASE ONE: CONCLUSION

Now we are done with the basic tuning of Phase One. The plane should now fly stable and smooth in calm conditions, NAV CRUISE, RTH and NAV POSHOLD modes should now work acceptable and your failsafe is ready. For new pilots it is now time to fly some batteries to get experience and confidence in your plane. After that, we can continue to PHASE TWO.

At this point I recommend you run through our Autolaunch Guide:

INAV AUTOLAUNCH (https://1drv.ms/b/s!Ar6QsGgoXRgqnLYOU_OioUAgBc06UA)

PHASE TWO: MANUAL FINE-TUNING

After finishing AUTOTUNE and flying around for some packs, maybe you are getting more confident and try to fly also in not that ideal conditions like gusty wind or fly with high speed, you will likely recognize that not everything is perfect. The plane is wobbling around in the wind or jittering on full throttle and fast dives and maybe also overshoots when stopping from fast rolls or loops. At this point this is absolutely normal because AUTOTUNE is only able to give you a basic PIFF controller tuning. But to get a real perfect tune, there are some more things to set up that cannot be determined automatically. This is the point where we need to look exactly how the plane behave to analyze what needs to be optimized in the tune.

PIFF OPTIMIZATION

As you might remember, the automatic tuning is done at very calm conditions. This is necessary to avoid wind turbulences influence the measurement of the overshoots causing wrong values. Therefore, the P-Value is set very low and there will be only minimal stabilization to counteract wind gusts. We need to optimize that manually and I’ll explain how. Also, the I-Term is set relatively low to avoid backshoots but sometimes it can be too low and causing slight drift. We need to be careful with the I-Term and I’ll explain you why.

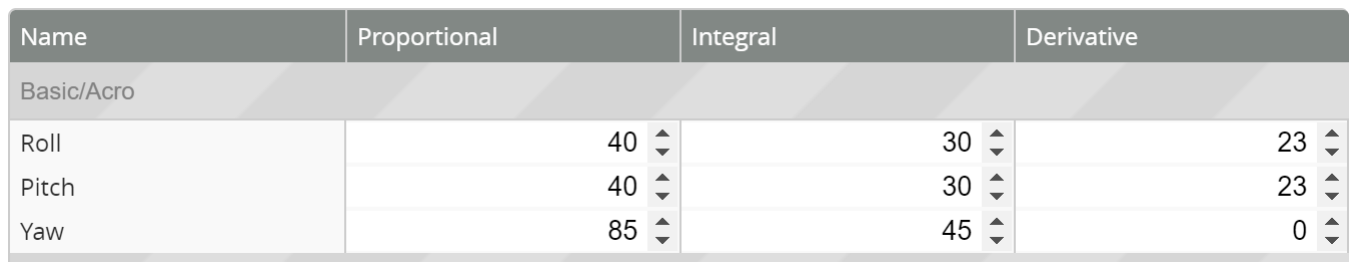
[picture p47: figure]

P-TUNING

To get a good P-Value for descent stabilization, it is important to find the correct weather conditions. A slightly windy day with some gusts is perfect for this but be careful that the wind is not too strong so as to be able to land safely.

Start flying normally. Watch how much it is bumping around in the wind, while there is no stick input. Always fly at low speeds but fast enough to get a stable and responsive flight. Then do some hard maneuvers from left to right and pitch up and down and watch the oscillations. The plane should not swing back and forth fast or more than 3 times when stopping from a rapid roll or pitch movement. On flying wings, the pitch can oscillate a bit quicker and more often due to the short fuselage. This is to check if the P value is too high. In this case you will get multiple swings around each axis.

If the plane is too bumpy and sluggish on straight flight and not oscillating more than 2 or 3 times on each axis when doing hard rolls and pitches, land the plane and raise the P gain on the axis that is not stable enough by about 20% or 1 step. Then do the same again until the roll stop oscillation gets too strong on each axis (3 or 4 swings on each axis), then go back the last step and you have finished the P tuning. We will get rid of the last overshoot oscillation later.

I-TUNING

The I-Term tuning is a little bit delicate and usually not necessary. But if your plane has some strange aerodynamic properties, it can be useful though. Planes like the Dart XL from ZOHD tend to nose up on high throttle and here it makes sense to have a higher I-Term to compensate for that, because the I-Term counteracts on slow drifts of attitude. Also, if a plane is nose heavy, it would cause a ‘nose up’ on high speeds due to the reflex that is needed to counteract the nose weight, but the I-Term will compensate for that. Too high I value can cause a dangerous tip stall or even flat spin if the airspeed gets too low and the plane aggressively tries to keep the nose up instead of letting it fall and gain speed. It will also cause massive rollbacks when stopping long rolls or loops.

If the plane drifts slowly away on roll or pitch, without any stick input, raise the I value a little bit. Try 10% steps as a good start. Only raise the I-Term on the axis that drifts away and then fly again. Fly around at low and high speed and watch for roll or pitch overshoots on hard maneuvers. Then fly a slight nose up and lower the throttle slowly until plane reaches stall speed. If the plane does not nose down and instead goes into a tip-stall or flat spin (only do that at a safe height), throttle up and gain back control. Then lower the Pitch I value again and test again until the stall is more stable and the nose dips on low airspeed.

After that, the I-Term tuning is done too.

FF-TUNING

The last value should not be touched after autotune but can be checked if it is still fine after P and I optimization. The FF-Term does the most work when flying the wing and translates the user input into correct control surface movement. To keep some room for P and I to work, even on hard maneuvers, the FF value should not use the full servo throw. You can check this on the bench by doing the following.

Plug a battery in the plane and make sure you have no flight mode active (ACRO) and manual mode on a switch. Take your transmitter and give the plane a full pitch input and look at the control surfaces. While holding the stick at full deflection, switch into MANUAL mode. At this moment, the control surfaces should move slightly to give even a bit more throw. Disabling MANUAL mode should move the control surfaces back a little bit. The difference should be about 10-15% of the servo throw. If the difference is smaller, you need to lower the FF gain a bit. If the difference is too high, just raise the FF value a bit. Do the same with the Roll-Axis and you are done. FF is not necessary for Rudder.

TPA-TUNING FOR HIGH-SPEED

Now we will come to the point that is very interesting for race-wing pilots, especially if you do proximity flying. All the tuning we have done so far, was done at low speeds to get as much stabilization as possible on the plane. The issue now is that high airspeeds will cause much more aggressive reactions of the plane to any control surface movement. As INAV does not account for that by default, we need to tell the FC, when to lower the control movements. The system to do that is called TPA (Throttle PID Attenuation). The TPA system relies on two values: TPA Percentage and TPA Setpoint. The TPA setpoint will mark the throttle value, where INAV starts to lower the PIFF controller values. The percentage is the amount of value reduction at full throttle. The PIFF controller will get lower linear, starting at the setpoint up to full throttle. This will counteract the over correction at high speeds and keeps the stabilization at a constant level. This is how to determine these values.

First of all, we need to check what the TPA setpoint needs to be. For that you launch the plane again. Fly with FPV and do a recording if possible. Also activate the throttle value in your OSD. Start flying in any stabilized flight mode at low throttle and rise it slowly. Do slight maneuvers and rise the throttle further very slowly and watch how the plane behaves. If the plane starts to jitter a bit or if it oscillates quickly after small but rapid movements, lower the throttle until it flies stable again. Note the throttle value and now you have determined your TPA setpoint.

Getting the correct TPA percentage is more a series of trial and error adjustments. The higher your motor power, the higher the TPA percentage at full throttle. On low powered planes, if the setpoint is already above 50% throttle, you can start with 20-30%. Fly again and slowly go up to full throttle. If the plane still jitters or oscillates at full throttle, rise the percentage by 10% and repeat the test. Do this until the plane flies smooth and stable at full throttle but ignore the slight overshoots on hard rolls or pitch movements. We will account for that next. After that, the TPA setpoint is tuned

and we can continue.

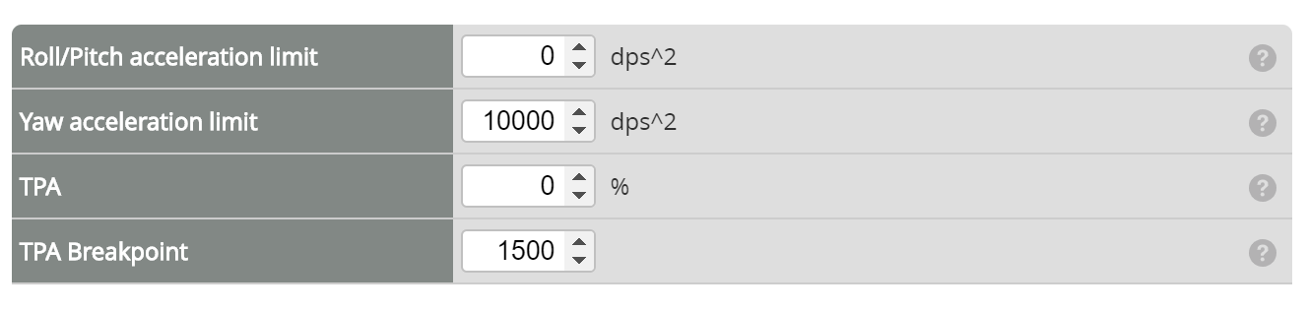
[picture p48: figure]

RATE ACCELLERATION FOR SMOOTHER FLIGHTS

After your plane is now tuned very well and hopefully nicely locked in position during flight, it is time to make hard maneuvers a bit smoother. As you might remember during PIFF Optimization, we left some oscillations in favor to more intense stabilization, when coming out of fast rolls and loops. To counteract that, we will now physically limit the acceleration for starting and stopping roll and pitch movements.

In PID tuning TAB You will find a value called “Roll/Pitch acceleration limit” and the name tells you the function of this. By default, the limit is disabled. Limiting the rate acceleration forces the flight controller to incrementally raise the roll and pitch movement instead of trying to force the full speed instantly, what it physically not possible. Smaller builds can easily reach their maximum rates quickly, but larger planes need some time to gain their full axis rates. For starting a roll or pitch movement, this limit is more an optical benefit to have a smoother and more natural movement. But when stopping a rapid movement, this can massively increase the stabilization behavior, because it lowers the amount of overshoot and oscillation on high P-Gains.

On small builds like 600mm race wings, a value between 1500 and 2000°/s² is a good value to start with. Crafts up to 1000mm can use lower values like 1200-1500°/s². Large Long-range crafts like a Skyhawk can be set to 1000°/s² or even lower. As a side effect, this limit will also apply to automatic flight modes like waypoint and avoids the rapid and stiff direction changes that INAV usually does.

BE CAREFUL: Setting the rate limit lower, will also reduce your maneuverability in case of an obstacle avoidance situation. So double check what you set here before the flight to avoid a situation where you can barely control your craft. For proximity flying this rate limit should be kept very high because it can cause a slight delay in your controls.

PHASE TWO: CONCLUSION

At this point, you have a craft that can be flown well in any situation with good stabilization, optimal rates and smooth flight. This counts for flights not only in ACRO mode but also for ANGLE and HORIZON flight modes.
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

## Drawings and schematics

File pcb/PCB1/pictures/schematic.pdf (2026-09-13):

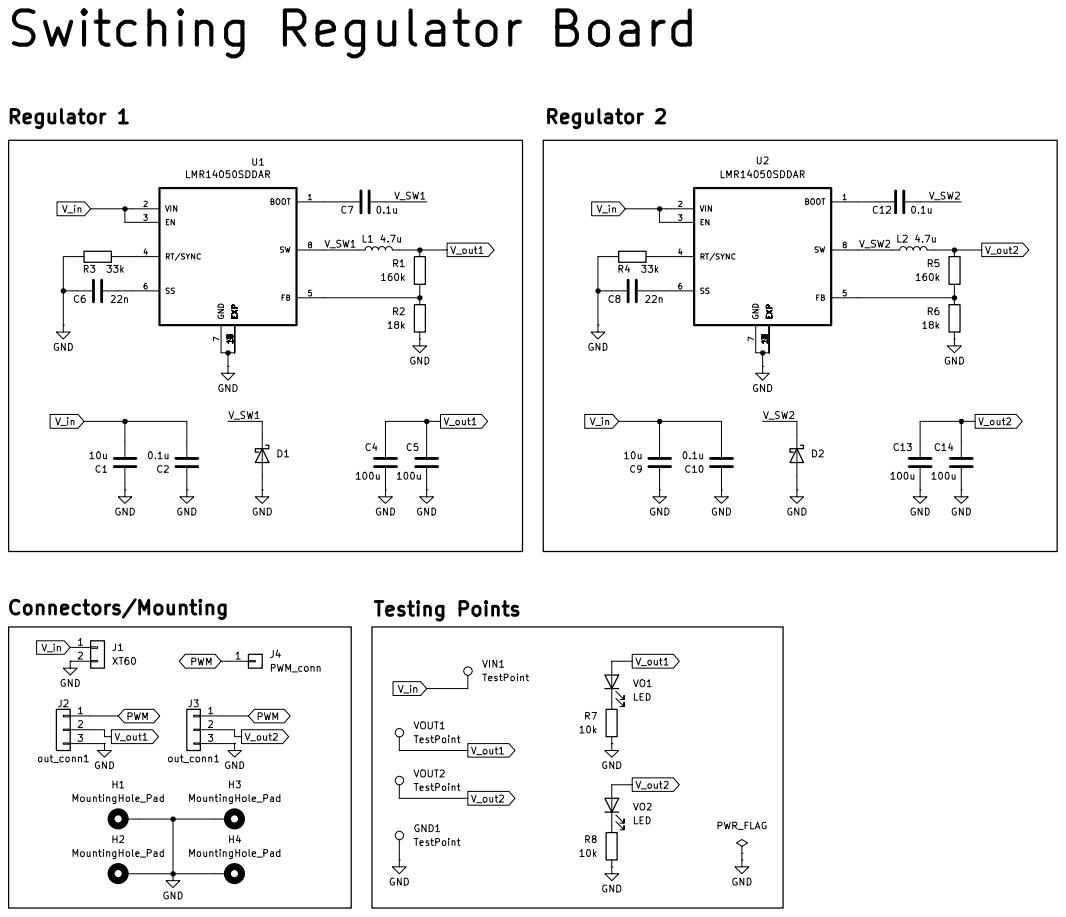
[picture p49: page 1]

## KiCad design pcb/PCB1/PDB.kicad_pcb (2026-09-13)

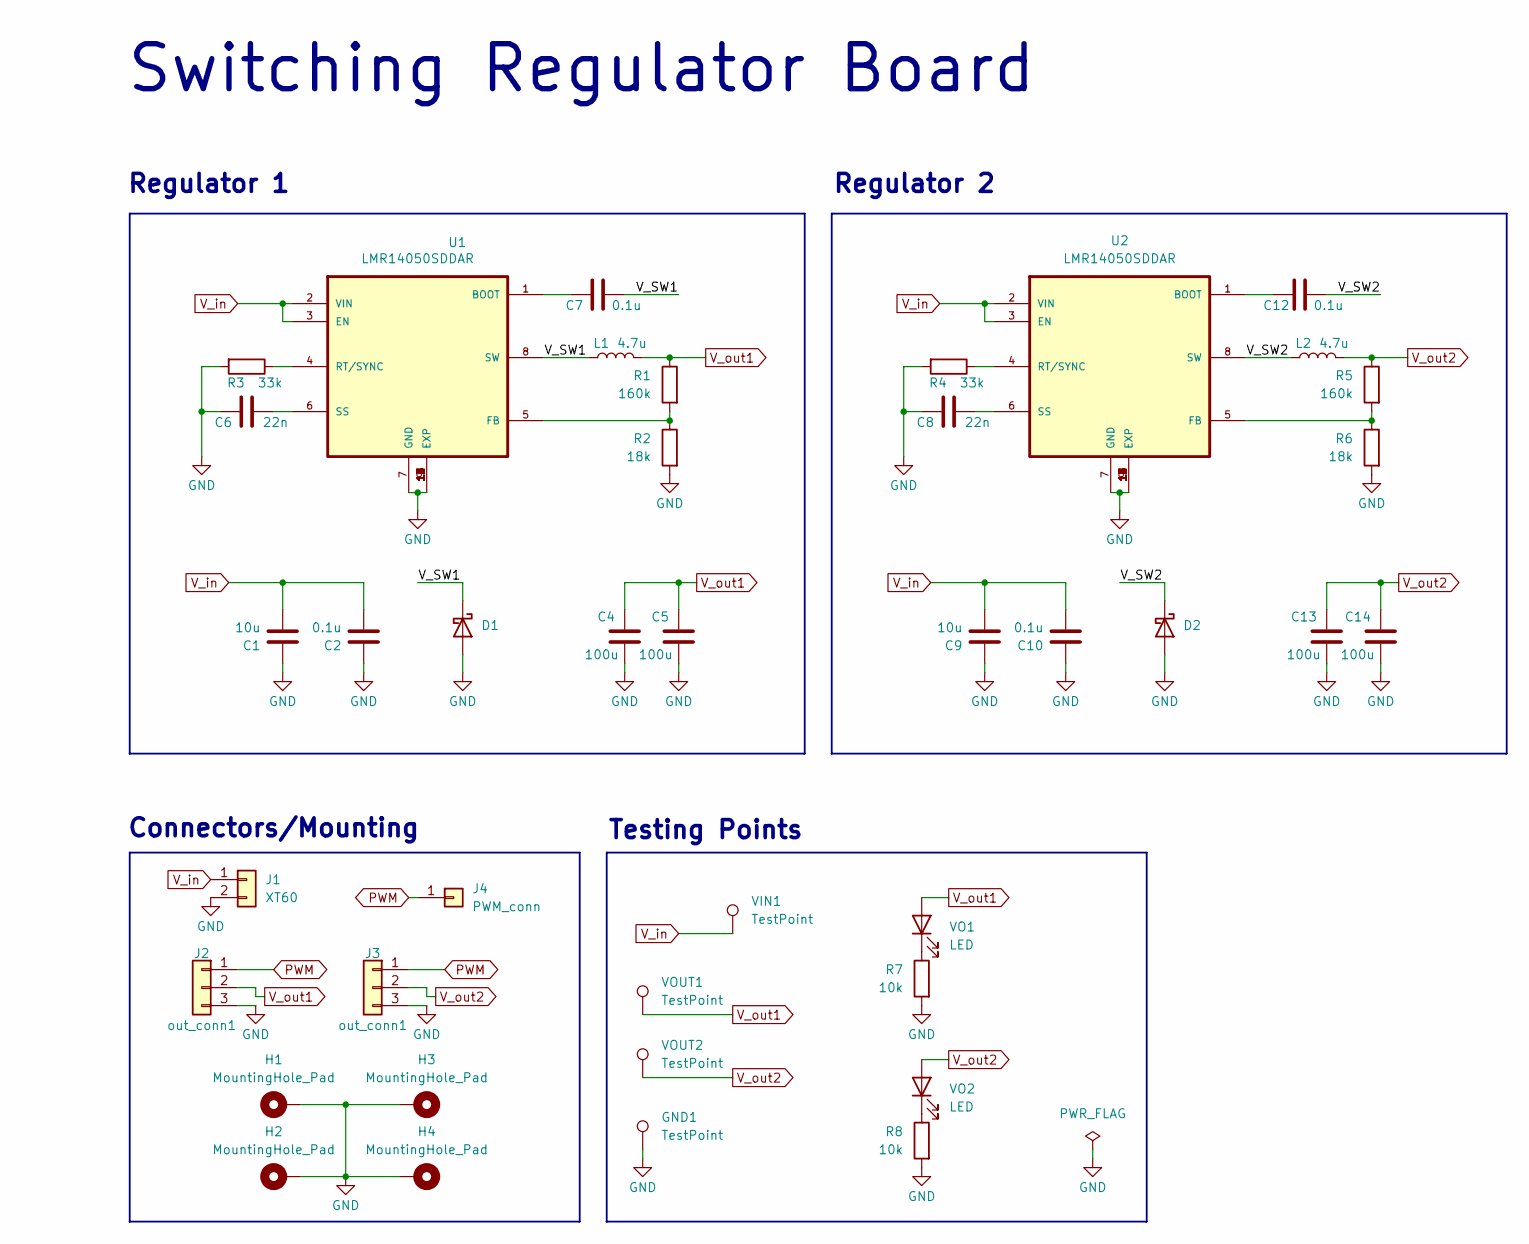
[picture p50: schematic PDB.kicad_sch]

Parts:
C1, C9: 10u; C_Radial_D5.0mm_H7.0mm_P2.00mm
C2, C7, C10, C12: 0.1u; C_0603_1608Metric_Pad1.08x0.95mm_HandSolder
C4, C5, C13, C14: 100u; C_Radial_D5.0mm_H7.0mm_P2.00mm
C6, C8: 22n; C_0603_1608Metric_Pad1.08x0.95mm_HandSolder
D1, D2: D_Schottky; SS54-Slkor
GND1: TestPoint; TestPoint_Pad_D1.0mm
H1, H2, H3, H4: MountingHole_Pad; MountingHole_2.2mm_M2_Pad_TopBottom
J1: XT60; AMASS_XT60-F_1x02_P7.20mm_Vertical
J2, J3: out_conn1; PinHeader_1x03_P2.54mm_Vertical
J4: PWM_conn; PinHeader_1x01_P2.54mm_Vertical
L1, L2: 4.7u; L_1210_3225Metric_Pad1.42x2.65mm_HandSolder
R1, R5: 160k; R_0805_2012Metric_Pad1.20x1.40mm_HandSolder
R2, R6: 18k; R_0805_2012Metric_Pad1.20x1.40mm_HandSolder
R3, R4: 33k; R_0805_2012Metric_Pad1.20x1.40mm_HandSolder
R7, R8: 10k; R_0805_2012Metric_Pad1.20x1.40mm_HandSolder
U1, U2: LMR14050SDDAR; VREG_LM5017MR_NOPB
VIN1: TestPoint; TestPoint_Pad_D1.0mm
VO1, VO2: LED; D_0805_2012Metric_Pad1.15x1.40mm_HandSolder
VOUT1, VOUT2: TestPoint; TestPoint_Pad_D1.0mm

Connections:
/V_SW1: C7.2, D1.1 (K), L1.1, U1.8 (SW)
/V_SW2: C12.2, D2.1 (K), L2.1, U2.8 (SW)
GND: C1.2, C2.2, C4.2, C5.2, C6.1, C8.1, C9.2, C10.2, C13.2, C14.2, D1.2 (A), D2.2 (A), GND1.1, H1.1, H2.1, H3.1, H4.1, J1.2, J2.3, J3.3, R2.2, R3.2, R4.2, R6.2, R7.2, R8.2, U1.7 (GND), U1.9 (EXP), U1.10 (EXP), U1.11 (EXP), U1.12 (EXP), U1.13 (EXP), U1.14 (EXP), U1.15 (EXP), U1.16 (EXP), U1.17 (EXP), U2.7 (GND), U2.9 (EXP), U2.10 (EXP), U2.11 (EXP), U2.12 (EXP), U2.13 (EXP), U2.14 (EXP), U2.15 (EXP), U2.16 (EXP), U2.17 (EXP)
unnamed: C7.1, U1.1 (BOOT)
unnamed: R1.2, R2.1, U1.5 (FB)
unnamed: R3.1, U1.4 (RT/SYNC)
unnamed: C6.2, U1.6 (SS)
unnamed: C12.1, U2.1 (BOOT)
unnamed: R5.2, R6.1, U2.5 (FB)
unnamed: R4.1, U2.4 (RT/SYNC)
unnamed: C8.2, U2.6 (SS)
unnamed: R7.1, VO1.1 (K)
unnamed: R8.1, VO2.1 (K)
PWM: J2.1, J3.1, J4.1
V_in: C1.1, C2.1, C9.1, C10.1, J1.1, U1.2 (VIN), U1.3 (EN), U2.2 (VIN), U2.3 (EN), VIN1.1
V_out1: C4.1, C5.1, J2.2, L1.2, R1.1, VO1.2 (A), VOUT1.1
V_out2: C13.1, C14.1, J3.2, L2.2, R5.1, VO2.2 (A), VOUT2.1

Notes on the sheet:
Testing Points
Connectors/Mounting
Switching Regulator Board
Regulator 1
Regulator 2

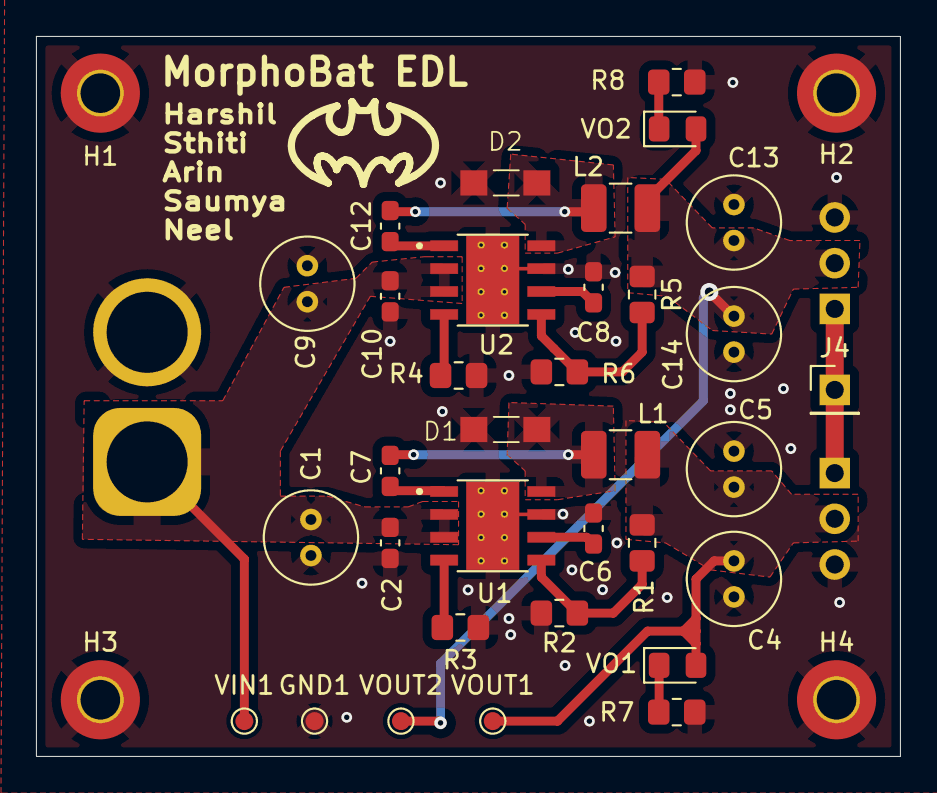
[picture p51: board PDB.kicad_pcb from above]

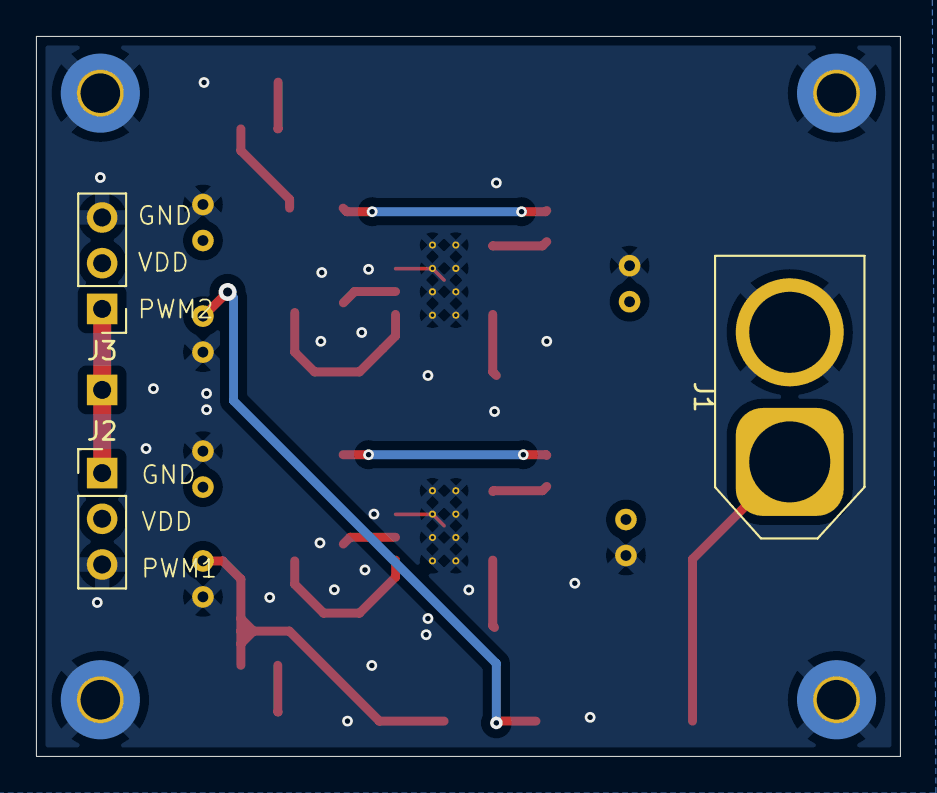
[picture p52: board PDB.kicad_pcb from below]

Board: 2 copper layers, 48.0 x 40.0 mm, 40 parts (3 on the bottom side), 17 nets.

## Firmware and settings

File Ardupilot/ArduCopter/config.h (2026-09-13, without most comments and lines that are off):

#pragma once
#include "defines.h"
#include "APM_Config.h"
#include <AP_ADSB/AP_ADSB_config.h>
#include <AP_Follow/AP_Follow_config.h>
#include <AC_Avoidance/AC_Avoidance_config.h>
#ifndef CONFIG_HAL_BOARD
#error CONFIG_HAL_BOARD must be defined to build ArduCopter
#endif
    # define ARMING_DELAY_SEC 2.0f
 # define FRAME_CONFIG   MULTICOPTER_FRAME
#if FRAME_CONFIG == HELI_FRAME
  # define RC_FAST_SPEED                        125
  # define WP_YAW_BEHAVIOR_DEFAULT              WP_YAW_BEHAVIOR_LOOK_AHEAD
#endif
#ifndef RC_FAST_SPEED
   #   define RC_FAST_SPEED 490
#endif
 # define RANGEFINDER_FILT_DEFAULT 0.5f     // filter for rangefinder distance
 # define SURFACE_TRACKING_TIMEOUT_MS  1000 // surface tracking target alt will reset to current rangefinder alt after this many milliseconds without a good rangefinder alt
 # define MAV_SYSTEM_ID          1
 # define GPS_HDOP_GOOD_DEFAULT         140     // minimum hdop that represents a good position.  used during pre-arm checks if fence is enabled
 #define FS_TERRAIN_TIMEOUT_MS          5000     // 5 seconds of missing terrain data will trigger failsafe (RTL)
 # define PREARM_MAX_ALT_DISPARITY_CM       100     // barometer and inertial nav altitude must be within this many centimeters
 # define FS_EKF_ACTION_DEFAULT         FS_EKF_ACTION_LAND  // EKF failsafe triggers land by default
 # define FS_EKF_THRESHOLD_DEFAULT      0.8f    // EKF failsafe's default compass and velocity variance threshold above which the EKF failsafe will be triggered
 # define EKF_ORIGIN_MAX_ALT_KM         50   // EKF origin and home must be within 50km vertically
# define FS_EKF_FILT_DEFAULT     5.0f    // frequency cutoff of EKF variance filters
 # define AUTOTUNE_ENABLED  1
 # define AC_NAV_GUIDED    1
# define MODE_ACRO_ENABLED 1
# define MODE_AUTO_ENABLED 1
# define MODE_BRAKE_ENABLED 1
# define MODE_CIRCLE_ENABLED 1
# define MODE_DRIFT_ENABLED 1
# define MODE_FLIP_ENABLED 1
#if AP_FOLLOW_ENABLED && AP_AVOIDANCE_ENABLED
#define MODE_FOLLOW_ENABLED 1
#else
#define MODE_FOLLOW_ENABLED 0
#endif
# define MODE_GUIDED_ENABLED 1
# define MODE_GUIDED_NOGPS_ENABLED 1
# define MODE_DRIVE_ENABLED 1
# define MODE_MORPH_ENABLED 1
# define MODE_LOITER_ENABLED 1
# define MODE_POSHOLD_ENABLED 1
# define MODE_RTL_ENABLED 1
# define MODE_SMARTRTL_ENABLED 1
# define MODE_SPORT_ENABLED 0
# define MODE_SYSTEMID_ENABLED HAL_LOGGING_ENABLED
# define MODE_THROW_ENABLED 1
# define MODE_ZIGZAG_ENABLED 1
# define MODE_TURTLE_ENABLED HAL_DSHOT_ENABLED && FRAME_CONFIG != HELI_FRAME
# define MODE_FLOWHOLD_ENABLED AP_OPTICALFLOW_ENABLED
# define WEATHERVANE_ENABLED 1
#if CONFIG_HAL_BOARD == HAL_BOARD_SITL
    #if FRAME_CONFIG == HELI_FRAME
        # define MODE_AUTOROTATE_ENABLED 1
    #else
        # define MODE_AUTOROTATE_ENABLED 0
    #endif
#else
    # define MODE_AUTOROTATE_ENABLED 0
#endif
 # define FLIGHT_MODE_1                  Mode::Number::DRIVE
 # define FLIGHT_MODE_2                  Mode::Number::MORPH
 # define FLIGHT_MODE_3                  Mode::Number::STABILIZE
 # define FLIGHT_MODE_4                  Mode::Number::STABILIZE
 # define FLIGHT_MODE_5                  Mode::Number::STABILIZE
 # define FLIGHT_MODE_6                  Mode::Number::STABILIZE
 # define FS_THR_VALUE_DEFAULT             975
 # define PILOT_TKOFF_ALT_DEFAULT           0     // default final alt above home for pilot initiated takeoff
 # define LAND_SPEED    50          // the descent speed for the final stage of landing in cm/s
 # define LAND_REPOSITION_DEFAULT   1   // by default the pilot can override roll/pitch during landing
 # define LAND_WITH_DELAY_MS        4000    // default delay (in milliseconds) when a land-with-delay is triggered during a failsafe event
 # define LAND_CANCEL_TRIGGER_THR   700     // land is cancelled by input throttle above 700
#define LAND_RANGEFINDER_MIN_ALT_CM 200
 # define LAND_DETECTOR_TRIGGER_SEC         1.0f    // number of seconds to detect a landing
 # define LAND_AIRMODE_DETECTOR_TRIGGER_SEC 3.0f    // number of seconds to detect a landing in air mode
 # define LAND_DETECTOR_MAYBE_TRIGGER_SEC   0.2f    // number of seconds that means we might be landed (used to reset horizontal position targets to prevent tipping over)
# define LAND_DETECTOR_ACCEL_LPF_CUTOFF     1.0f    // frequency cutoff of land detector accelerometer filter
# define LAND_DETECTOR_ACCEL_MAX            1.0f    // vehicle acceleration must be under 1m/s/s
# define LAND_DETECTOR_VEL_Z_MAX              1.0f    // vehicle vertical velocity must be under 1m/s
 # define ACRO_LEVEL_MAX_ANGLE      3000 // maximum lean angle in trainer mode measured in centidegrees
 # define ACRO_LEVEL_MAX_OVERSHOOT  1000 // maximum overshoot angle in trainer mode when full roll or pitch stick is held in centidegrees
 #define ACRO_BALANCE_ROLL          1.0f
 #define ACRO_BALANCE_PITCH         1.0f
 #define ACRO_RP_EXPO_DEFAULT       0.3f    // ACRO roll and pitch expo parameter default
 #define ACRO_Y_EXPO_DEFAULT        0.0f    // ACRO yaw expo parameter default
 #define ACRO_THR_MID_DEFAULT       0.0f
 #define ACRO_RP_RATE_DEFAULT      360      // ACRO roll and pitch rotation rate parameter default in deg/s
 #define ACRO_Y_RATE_DEFAULT       202.5    // ACRO yaw rotation rate parameter default in deg/s
 # define RTL_ALT_FINAL             0       // the altitude, in cm, the vehicle will move to as the final stage of Returning to Launch.  Set to zero to land.
 # define RTL_ALT                   1500    // default alt to return to home in cm, 0 = Maintain current altitude
 # define RTL_ALT_MIN               30     // min height above ground for RTL (i.e 30cm)
 # define RTL_CLIMB_MIN_DEFAULT     0       // vehicle will always climb this many cm as first stage of RTL
 # define RTL_CONE_SLOPE_DEFAULT    3.0f    // slope of RTL cone (height / distance). 0 = No cone
 # define RTL_MIN_CONE_SLOPE        0.5f    // minimum slope of cone
 # define RTL_LOITER_TIME           5000    // Time (in milliseconds) to loiter above home before beginning final descent
#ifndef WP_YAW_BEHAVIOR_DEFAULT
 # define WP_YAW_BEHAVIOR_DEFAULT   WP_YAW_BEHAVIOR_LOOK_AT_NEXT_WP_EXCEPT_RTL
#endif
 # define YAW_LOOK_AHEAD_MIN_SPEED  100             // minimum ground speed in cm/s required before copter is aimed at ground course
 # define SUPER_SIMPLE_RADIUS       1000
 # define ROLL_PITCH_YAW_INPUT_MAX      4500        // roll, pitch and yaw input range
 # define DEFAULT_ANGLE_MAX         3000            // ANGLE_MAX parameters default value
 # define BRAKE_MODE_SPEED_Z     250 // z-axis speed in cm/s in Brake Mode
 # define BRAKE_MODE_DECEL_RATE  750 // acceleration rate in cm/s/s in Brake Mode
 # define POSHOLD_BRAKE_RATE_DEFAULT    8       // default POSHOLD_BRAKE_RATE param value.  Rotation rate during braking in deg/sec
 # define POSHOLD_BRAKE_ANGLE_DEFAULT   3000    // default POSHOLD_BRAKE_ANGLE param value.  Max lean angle during braking in centi-degrees
# define THR_DZ_DEFAULT         100             // the deadzone above and below mid throttle while in althold or loiter
 # define PILOT_VELZ_MAX    250     // maximum vertical velocity in cm/s
 # define PILOT_ACCEL_Z_DEFAULT 250 // vertical acceleration in cm/s/s while altitude is under pilot control
 # define PILOT_Y_RATE_DEFAULT  202.5   // yaw rotation rate parameter default in deg/s for all mode except ACRO
 # define PILOT_Y_EXPO_DEFAULT  0.0     // yaw expo parameter default for all mode except ACRO
# define AUTO_DISARMING_DELAY  10
# define THROW_HIGH_SPEED       500.0f  // vehicle much reach this total 3D speed in cm/s (or be free falling)
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

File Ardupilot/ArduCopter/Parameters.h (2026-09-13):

#pragma once

#define AP_PARAM_VEHICLE_NAME copter

#include <AP_Common/AP_Common.h>
#include "RC_Channel_Copter.h"
#include <AP_Proximity/AP_Proximity.h>

#if MODE_FOLLOW_ENABLED
 # include <AP_Follow/AP_Follow.h>
#endif
#if WEATHERVANE_ENABLED
 #include <AC_AttitudeControl/AC_WeatherVane.h>
#endif

// Global parameter class.
//
class Parameters {
public:
    // The version of the layout as described by the parameter enum.
    //
    // When changing the parameter enum in an incompatible fashion, this
    // value should be incremented by one.
    //
    // The increment will prevent old parameters from being used incorrectly
    // by newer code.
    //
    static const uint16_t        k_format_version = 120;

    // Parameter identities.
    //
    // The enumeration defined here is used to ensure that every parameter
    // or parameter group has a unique ID number.  This number is used by
    // AP_Param to store and locate parameters in EEPROM.
    //
    // Note that entries without a number are assigned the next number after
    // the entry preceding them. When adding new entries, ensure that they
    // don't overlap.
    //
    // Try to group related variables together, and assign them a set
    // range in the enumeration. Place these groups in numerical order
    // at the end of the enumeration.
    //
    // WARNING: Care should be taken when editing this enumeration as the
    //          AP_Param load/save code depends on the values here to identify
    //          variables saved in EEPROM.
    //
    //
    enum {
        // Layout version number, always key zero.
        //
        k_param_format_version = 0,
        k_param_software_type, // deprecated
        k_param_ins_old,                        // *** Deprecated, remove with next eeprom number change
        k_param_ins,                            // libraries/AP_InertialSensor variables
        k_param_NavEKF2_old, // deprecated - remove
        k_param_NavEKF2,
        k_param_g2, // 2nd block of parameters
        k_param_NavEKF3,
        k_param_can_mgr,
        k_param_osd,

        // simulation
        k_param_sitl = 10,

        // barometer object (needed for SITL)
        k_param_barometer,

        // scheduler object (for debugging)
        k_param_scheduler,

        // relay object
        k_param_relay,

        // (old) EPM object
        k_param_epm_unused,

        // BoardConfig object
        k_param_BoardConfig,

        // GPS object
        k_param_gps,

        // Parachute object
        k_param_parachute,

        // Landing gear object
        k_param_landinggear,    // 18

        // Input Management object
        k_param_input_manager,  // 19
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

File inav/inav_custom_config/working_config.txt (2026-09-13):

# diff all 

# version
# INAV/SPEEDYBEEF405V4 8.0.0 Mar 13 2025 / 15:18:49 (2ebe75b2) 
# GCC-13.2.1 20231009

# start the command batch
batch start

# reset configuration to default settings
defaults noreboot

# resources

# Timer overrides
timer_output_mode 2 MOTORS
timer_output_mode 3 MOTORS
timer_output_mode 7 SERVOS

# Outputs [servo]

# safehome

# Fixed Wing Approach

# geozone

# geozone vertices

# features
feature PWM_OUTPUT_ENABLE

# beeper

# blackbox
blackbox -NAV_ACC
blackbox NAV_POS
blackbox NAV_PID
blackbox MAG
blackbox ACC
blackbox ATTI
blackbox RC_DATA
blackbox RC_COMMAND
blackbox MOTORS
blackbox -GYRO_RAW
blackbox -PEAKS_R
blackbox -PEAKS_P
blackbox -PEAKS_Y
blackbox SERVOS

# Receiver: Channel map

# Ports

# LEDs

# LED color

# LED mode_color

# Modes [aux]
aux 0 0 0 1950 2050
aux 1 47 4 1525 2100
aux 2 48 4 900 1475

# Adjustments [adjrange]

# Receiver rxrange

# temp_sensor

# Mission Control Waypoints [wp]
#wp 0 invalid

# OSD [osd_layout]

# Programming: logic
logic 0 1 -1 3 1 5 0 1500 0
logic 1 0 -1 12 0 0 0 0 0

# Programming: global variables

# Programming: PID controllers

# OSD: custom elements

# master
set gyro_main_lpf_hz = 90
set dynamic_gyro_notch_q = 250
set dynamic_gyro_notch_min_hz = 60
set dynamic_gyro_notch_mode = 3D
set setpoint_kalman_q = 200
set gyro_zero_x = 3
set gyro_zero_y = 9
set acc_hardware = ICM42605
set align_mag = CW270FLIP
set mag_hardware = NONE
set baro_hardware = SPL06
set serialrx_provider = CRSF
set blackbox_rate_denom = 2
set motor_pwm_protocol = DSHOT300
set failsafe_procedure = DROP
set applied_defaults = 5
set airmode_type = THROTTLE_THRESHOLD

# control_profile
control_profile 1

set mc_p_pitch = 44
set mc_i_pitch = 82
set mc_d_pitch = 29
set mc_cd_pitch = 110
set mc_i_roll = 75
set mc_d_roll = 26
set mc_cd_roll = 100
set mc_p_yaw = 45
set mc_i_yaw = 80
set mc_cd_yaw = 100
set dterm_lpf_hz = 85
set mc_iterm_relax = RPY
set d_boost_min =  1.000
set d_boost_max =  1.200
set antigravity_gain =  2.000
set antigravity_accelerator =  5.000
set smith_predictor_delay =  1.768
set tpa_rate = 20
set tpa_breakpoint = 1200
set rc_expo = 80
set rc_yaw_expo = 80
set roll_rate = 70
set pitch_rate = 70
set yaw_rate = 60
set ez_enabled = ON
set ez_filter_hz = 90
set ez_response = 101
set ez_damping = 115
set ez_rate = 134
set ez_expo = 118

# control_profile
control_profile 2

set mc_iterm_relax = RPY
set d_boost_min =  0.800
set d_boost_max =  1.200
set antigravity_gain =  2.000
set antigravity_accelerator =  5.000
set tpa_rate = 20
set tpa_breakpoint = 1200

# control_profile
control_profile 3

set mc_iterm_relax = RPY
set d_boost_min =  0.800
set d_boost_max =  1.200
set antigravity_gain =  2.000
set antigravity_accelerator =  5.000
set tpa_rate = 20
set tpa_breakpoint = 1200

# mixer_profile
mixer_profile 1

set model_preview_type = 3
set motorstop_on_low = OFF

# Mixer: motor mixer

mmix reset

mmix 0  1.000 -1.000  1.000 -1.000
mmix 1  1.000 -1.000 -1.000  1.000
mmix 2  1.000  1.000  1.000  1.000
mmix 3  1.000  1.000 -1.000 -1.000

# Mixer: servo mixer
smix reset

smix 0 1 5 100 0 0
smix 1 2 4 100 0 0

# mixer_profile
mixer_profile 2


# Mixer: motor mixer

# Mixer: servo mixer

# battery_profile
battery_profile 1


# battery_profile
battery_profile 2


# battery_profile
battery_profile 3


# restore original profile selection
control_profile 1
mixer_profile 1
battery_profile 1

# save configuration
save

# 

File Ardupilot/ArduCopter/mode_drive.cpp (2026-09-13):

#include "Copter.h"

//#include "AP_Math.h"  // Ensure you include this

/*
 * Init and run calls drive mode
 */
bool ModeDrive::init(bool ignore_checks) 
{
    // motors->set_desired_spool_state(AP_Motors::DesiredSpoolState::SHUT_DOWN);
        motors->rc_write(1, 0);
        motors->rc_write(2, 0);
        motors->rc_write(3, 0);
        motors->rc_write(4, 0);
        // Print debug information to SITL 
    return true;
}

// stabilize_run - runs the main stabilize controller
// should be called at 100hz or more
void ModeDrive::run()
{
    // apply simple mode transform to pilot inputs
    update_simple_mode();
        motors->rc_write(1, 0);
        motors->rc_write(2, 0);
        motors->rc_write(3, 0);
        motors->rc_write(4, 0);

        // Define PWM thresholds (these depend on RC calibration)
    // constexpr int16_t YAW_CENTER = 1500;  // Neutral position
    // constexpr int16_t DEADZONE = 50;      // Small buffer to avoid unintended movement
    // constexpr int16_t YAW_LEFT = 1300;    // Example left turn threshold
    // constexpr int16_t YAW_RIGHT = 1700;   // Example right turn threshold

    //uint16_t speed_min = 0000;  // Get servo_min (PWM min)
    //uint16_t speed_max = 2000;  // Get servo_max (PWM max)

    // convert pilot input to lean angles
    // float target_roll, target_pitch;
    // get_pilot_desired_lean_angles(target_roll, target_pitch, copter.aparm.angle_max, copter.aparm.angle_max);

    // get pilot's desired yaw rate
    //hal.console->printf("ModeDrive Running...\n");
    float target_left_right = channel_yaw->get_radio_in();
    float rover_forward = channel_throttle->get_radio_in(); 

    rover_forward = constrain_int16(rover_forward,0,2000);
    target_left_right = constrain_int16(target_left_right, 0, 2000);
    // int calc_final_pwm = rover_forward;
    // // calc_final_pwm = AP_Math::constrain(rover_forward, 1000, 2000);
    // calc_final_pwm = (rover_forward<2000? (rover_forward>1000? rover_forward: 1000) : 2000);
    // int pwm = AP_Math::constrain(target_left_right, 1000, 2000);


    // if (rover_forward > 1500) {
    //     motors->rc_write(4, calc_final_pwm);
    //     motors->rc_write(5, 0);
    //     motors->rc_write(6, calc_final_pwm);
    //     motors->rc_write(7, 0);
    //     hal.console->printf("Target Left/Right: %.2f, Rover Forward: %.2f, PWM: %d\n", 
    //                     target_left_right, rover_forward, calc_final_pwm);
    // } 

    // else
    // {
    //     motors->rc_write(4, 0);
    //     motors->rc_write(5, 0);
    //     motors->rc_write(6, 0);
    //     motors->rc_write(7, 0);
    // }
    // }
    // int pwm = target_left_right; // multipled by const. factor
    // pwm = (target_left_right<2000? (target_left_right>1000? target_left_right: 1000) : 2000);
    //float left_speed = rover_forward -target_left_right;
    //float right_speed = rover_forward + target_left_right;

    if(950<target_left_right && target_left_right<1050)
    {
        u_int16_t a = (rover_forward>1000? 2*(rover_forward-1000) : 0);
        u_int16_t b = (rover_forward>1000? 0 : 2*(1000-rover_forward));

        motors->rc_write(4, a);
        motors->rc_write(5, b);
        motors->rc_write(6, a);
        motors->rc_write(7, b);
    }

    if(950>=target_left_right) //left
    {
        u_int16_t val1 = rover_forward-1000;
        u_int16_t val2 = 1000 - rover_forward ;
        u_int16_t a = (rover_forward>1000? val1*2 : 0);
        u_int16_t b = (rover_forward>1000? 0 : val2*2);

        motors->rc_write(4, a);
        motors->rc_write(5, b);
        motors->rc_write(6, b);
        motors->rc_write(7, a);
    }

    if(target_left_right>=1050) //right
    {
        u_int16_t a = (rover_forward>1000? (rover_forward-1000)*2 : 0);
        u_int16_t b = (rover_forward>1000? 0 : (1000-rover_forward)*2);

        motors->rc_write(4, b);
        motors->rc_write(5, a);
        motors->rc_write(6, a);
        motors->rc_write(7, b);
    }
        // Print debug information to SITL console
        //hal.console->printf("Target Left/Right: %.2f, Rover Forward: %.2f, Left PWM: %.2f Right PWM: %.2f\n", target_left_right, rover_forward, left_speed, right_speed);
    // }

    // else if (target_left_right < (YAW_CENTER + DEADZONE)){

    //     //int pwm = target_left_right; // multipled by const. factor
    //     motors->rc_write(4, pwm);
    //     motors->rc_write(5, 0);
    //     motors->rc_write(7, pwm);
    //     motors->rc_write(6, 0);

    //         }
    // else{
    //     if (rover_forward > 500){
    //                 motors->rc_write(4, calc_final_pwm);
    //         motors->rc_write(5, 0);
    //         motors->rc_write(6, calc_final_pwm);
    //         motors->rc_write(7, 0);
    //         hal.console->printf("Target Left/Right: %.2f, Rover Forward: %.2f, PWM: %d\n", 
    //                         target_left_right, rover_forward, calc_final_pwm);

    //     }
    //         else
    //     {
    //         motors->rc_write(4, 0);
    //         motors->rc_write(5, 0);
    //         motors->rc_write(6, 0);
    //         motors->rc_write(7, 0);
    //     }
    // }
    
    // can I use this for speed? Is pwm single going to be according to the throttle set? - Sthiti


}
